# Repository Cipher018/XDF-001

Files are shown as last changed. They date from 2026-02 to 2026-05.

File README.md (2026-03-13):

# XDF-001

## Introduction

### What is XDF-001?

The **XDF-001**, or **Experimental Drone Fighter Model 001**, is a flight platform based on the P-51 Mustang airframe. Its experimental objective is to achieve a multi-role aircraft capable of both aerobatic flight and payload transport. Additionally, the XDF-001 platform seeks to demonstrate the viability of implementing simple autonomous capabilities in RC drones using vector operations, alongside data visualization via the **XDF-001 Control** application.

### Motivation

The motivation for this project stems from an interest in military aviation and aeronautics, as well as addressing the economic barriers within the RC aircraft community. Developing an aircraft within the ESP32 ecosystem helps overcome financial constraints, enabling the transition beyond typical 8-inch drones to larger-scale aircraft at equally competitive prices.

Another key motivation is the code's iterative potential; it can be adapted and modified for a myriad of missions and other types of aircraft and vehicles, allowing for extensive iteration and versatility.

### Objectives

The primary objective is to develop a fixed-wing platform based on the ESP32 ecosystem, capable of both radio control and simple autonomous maneuvers such as waypoint navigation or orbiting.

The secondary objectives are:

- Development of a telemetry visualization and control application for the flight platform.
- Study of various aerodynamic configurations to maximize the stability-to-top-speed ratio.
- Study of ESP32 behavior in handling real-time vector operations and autonomous capabilities.
- Development of a payload bay within the platform for payload transport.

### Architecture

As previously mentioned, the project is based on the ESP32 ecosystem and programmed using the Arduino IDE. However, communication between the ground ESP32 and the PC utilizes a binary system, enabling both command transmission and telemetry reception via USB serial. For a comprehensive study of the firmware architecture, please refer to the **[Documentation](Documentation/)** folder: check the diagrams section for data flows or the PDF section for function documentation.

## Project Parts

Below is a brief description of the repository's main folders and their contents:

### [CAD](CAD/)

Contains all CAD modeling files, including the root file modeled in FreeCAD and `.stp` files for the aircraft and PCB, as well as 3D models for the modules used.

<p align="center">
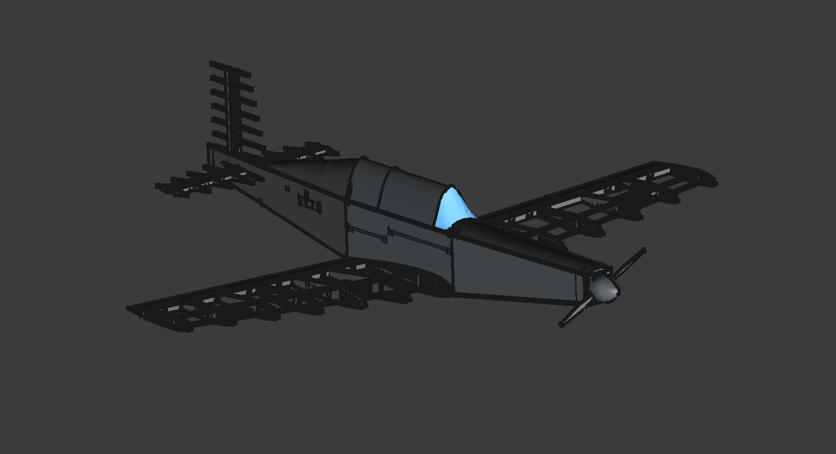
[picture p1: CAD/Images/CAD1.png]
CAD Model 1
  
  <br>
  <em>CAD Model 1</em>
</p>

<p align="center">
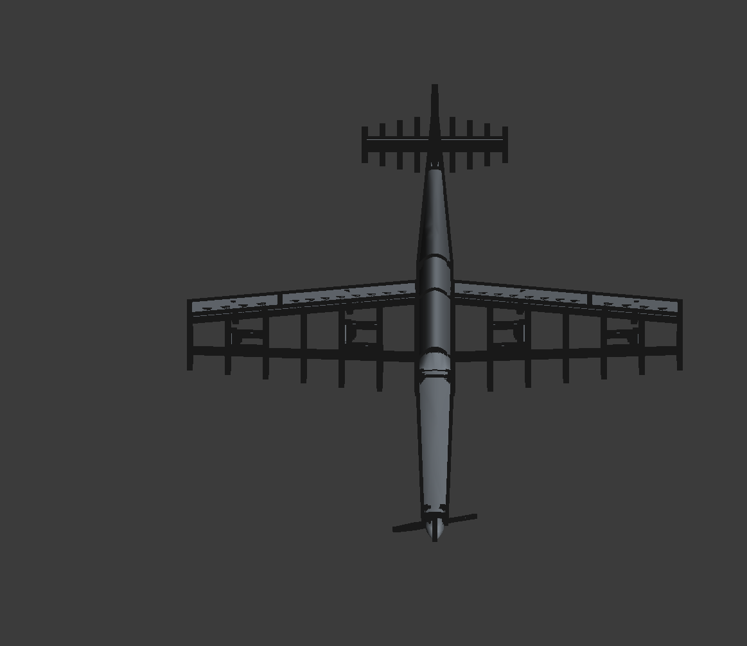
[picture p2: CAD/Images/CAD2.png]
CAD Model 2
  
  <br>
  <em>CAD Model 2</em>
</p>

### [Firmware](Firmware/)

Contains all ESP32 code, divided into air and ground sections. This includes communication functions, vector calculations, etc.

### [PCB](PCB/)

Contains all electronics-related files, including schematics, `.pcb` files, and manufacturing Gerbers.

<p align="center">
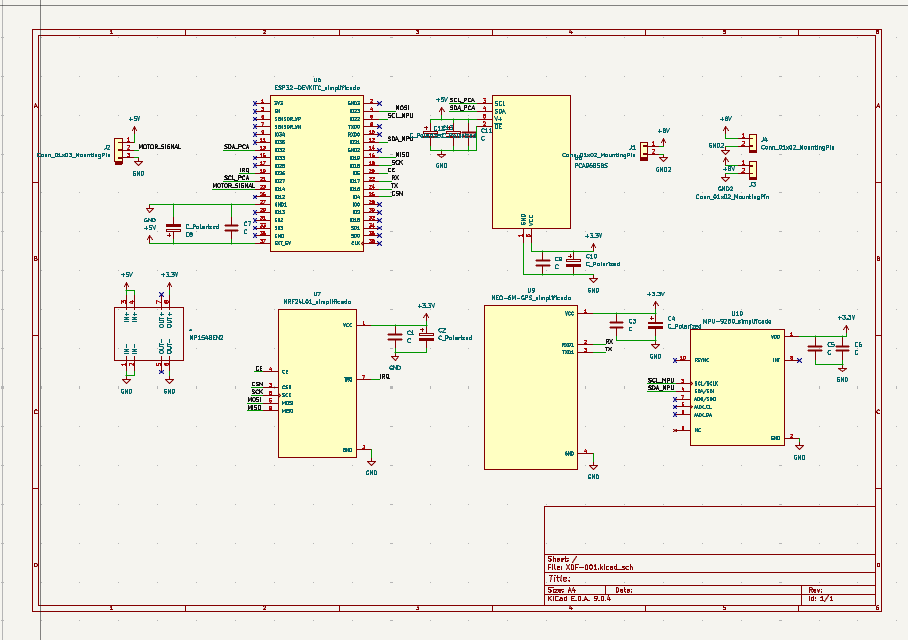
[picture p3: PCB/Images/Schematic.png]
PCB Schematic
  
  <br>
  <em>PCB Schematic</em>
</p>

<p align="center">
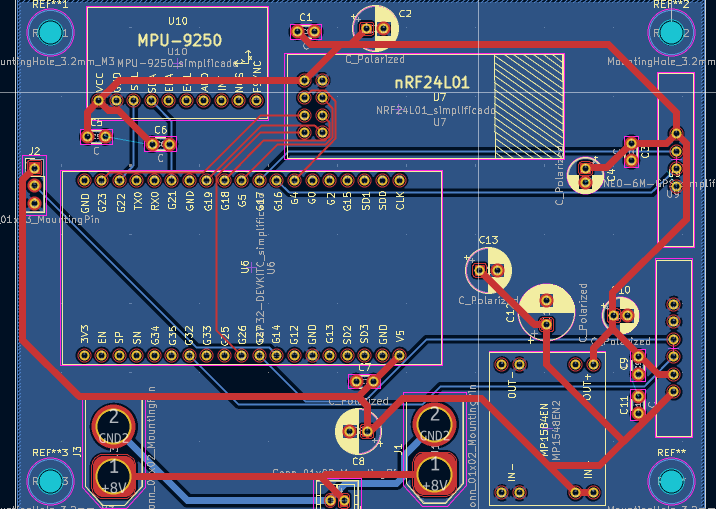
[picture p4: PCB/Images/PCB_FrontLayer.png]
PCB Front Layer
  
  <br>
  <em>PCB Front layer</em>
</p>

<p align="center">
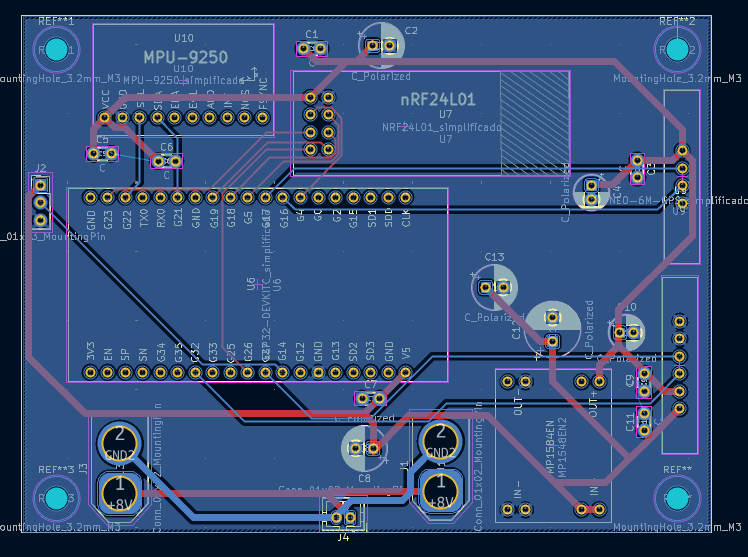
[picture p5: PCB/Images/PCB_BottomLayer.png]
PCB Back Layer
  
  <br>
  <em>PCB Back Layer</em>
</p>

<p align="center">
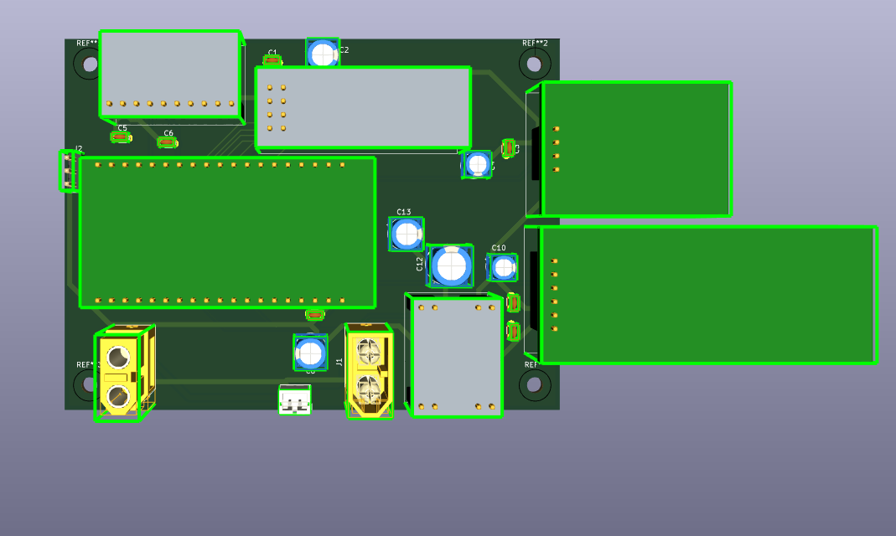
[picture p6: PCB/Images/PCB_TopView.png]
PCB Top view
  
  <br>
  <em>PCB Top view</em>
</p>

<p align="center">
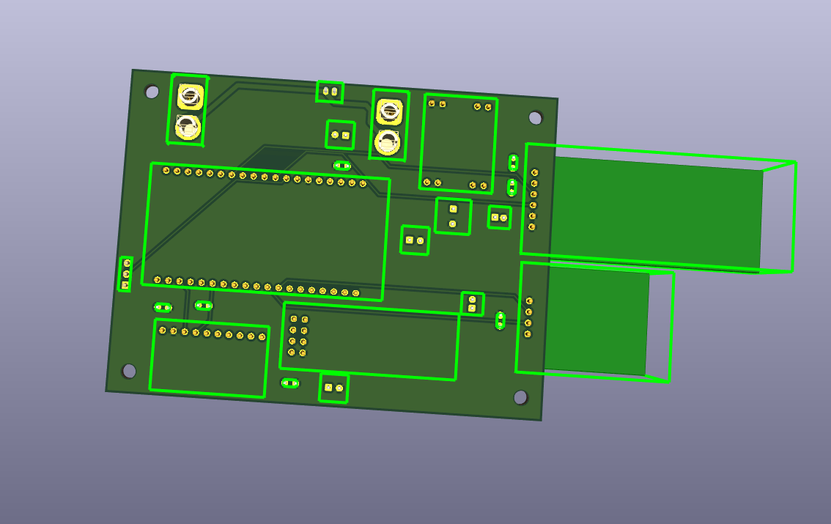
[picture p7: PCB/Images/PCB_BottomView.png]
PCB Bottom
  
  <br>
  <em>PCB Bottom view</em>
</p>

<p align="center">
  Wiring Diagram
  <br>
  <em>Referential Wiring Diagram of the aircraft</em>
</p>

### [XDF-001 Control](XDF-001_Control/)

Dedicated strictly to the visualization and control application. Contains all backend and frontend code.

### [References](References/)

Contains all structural references and concepts adopted from various creators for the project's construction.

### [Documentation](Documentation/)

Contains flowcharts and a detailed PDF explaining the application code, autonomous functions, and vector-based calculations.

### [Construction Manual](Construction%20Manual/)

PDF file detailing the aircraft construction method and key considerations for assembly.

## Changelog

### V0.0.0

Base project files have been exported, including code prototypes for both the ground and air sections. This release also includes the prototype for the control and telemetry application, as well as the PCB rendering, schematics, and CAD files.

## Roadmap

### V0.1.0

Completion of integration with Excel and SQL databases for the control and telemetry application.
Theoretical completion of the ground and air section code, enabling remote flight capabilities without telemetry and video visualization.

### V0.2.0

Achievement of initial flight tests, featuring full integration between the ground section and the control and telemetry application.
Initial implementation of autonomous functions, such as navigating to a designated point at a predefined altitude.

## FAQ

### What is the cost of the project?

The cost of the project varies depending on the dimensions of the flight platform and the components selected. For instance, opting to exclude the camera or telemetry functions can result in a cost of approximately $30. Conversely, selecting premium components can increase the cost to the order of $200 or more.

### Can I adapt this project?

Yes, under the license provided, I grant permission for the project to be modified to suit individual needs. In fact, adaptability is one of the core objectives of this project.

### What types of peripherals can I use to control the drone?

Any peripheral is acceptable provided it can be read by the ESP32 microcontroller. In this instance, a console controller was used, but joysticks, keyboards, mice, or any HID device are also compatible.

### How is the visualization and telemetry application used?

#### User Mode (Run Executable)

To use the application as a final user:

**Option A: Installer (Recommended)**

1. Navigate to `XDF-001_Control/out/make/squirrel.windows/x64/`.
2. Run `xdf-001_control-1.0.0 Setup.exe`.
3. The app will install and open automatically.

**Option B: Portable (Direct Run)**

1. Navigate to `XDF-001_Control/out/xdf-001_control-win32-x64/`.
2. Run `xdf-001_control.exe` directly.
3. No installation required. (You can also share the `out/make/zip` file).

#### Developer Mode (Run from Source)

If you want to modify the code or debug:

1. **Prerequisites**: Ensure [Node.js](https://nodejs.org/) (LTS) is installed.
2. Open a terminal in `XDF-001_Control`.
3. Install dependencies: `npm install`.
4. Start the app: `npm start`.

#### Build Mode (Create Executable)

To generate the `.exe` file yourself:

1. Follow the **Developer Mode** steps to set up the environment.
2. Run the build command: `npm run make`.
3. The output files will be created in the `out/` folder.

## Bill of Materials

| Item | Description | Quantity | Unit price | Total Price | Source | Running Total ($ with Tax) |
| --- | --- | --- | --- | --- | --- | --- |
| ESP-32 Devkit 38 pins | Dev board that will allow processing of telemetry, air-to-ground communication and autonomous operations based on vector operations | 1 | 4,23 | 4,23 | [Aliexpress](https://es.aliexpress.com/item/1005001838731651.html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"order"%3A"36"%2C"eval"%3A"1"%2C"fromPage"%3A"search"%7D&pdp_npi=6%40dis%21USD%213.34%213.34%21%21%213.34%213.34%21%4021033d9d17668726156532986ee92f%2112000030215458678%21sea%21CL%210%21ABX%211%210%21n_tag%3A-29910%3Bd%3Aeb55f528%3Bm03_new_user%3A-29895&curPageLogUid=kPFgvXo63lz3&utparam-url=scene%3Asearch%7Cquery_from%3A%7Cx_object_id%3A1005001838731651%7C_p_origin_prod%3A) | 5,03 |
| PCA9685 Servomotor Driver | Servomotor driver that allows control of up to 16 servomotors using only 2 pins, mainly used to avoid using all the pins of the ESP32 and for more sophisticated control via binary control | 1 | 1,2 | 1,2 | [Aliexpress](https://es.aliexpress.com/item/1005010790150348.html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,scm-url:1007.40050.354490.0,pvid:1402e862-8566-486e-90f8-f426f7e59b77,tpp_buckets:668%232846%238116%232002&pdp_ext_f=%7B"order"%3A"7"%2C"spu_best_type"%3A"price"%2C"eval"%3A"1"%2C"sceneId"%3A"30050"%2C"fromPage"%3A"recommend"%7D&pdp_npi=6%40dis%21USD%218.09%211.20%21%21%2155.58%218.25%21%402101e07217707498748102094ee684%2112000053516946348%21rec%21CL%21%21ABX%211%210%21n_tag%3A-29910%3Bd%3Aeb55f528%3Bm03_new_user%3A-29895%3BpisId%3A5000000197836568&utparam-url=scene%3ApcDetailTopMoreOtherSeller%7Cquery_from%3A%7Cx_object_id%3A1005010790150348%7C_p_origin_prod%3A) | 1,43 |
| nRF24l01+PLA Module | Radio module that allows medium-range air-to-ground communication without major interference; a PLA antenna is added to maximize range. | 2 | 2,31 | 4,62 | [Aliexpress](https://es.aliexpress.com/item/1005005392489486.html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"order"%3A"6"%2C"fromPage"%3A"search"%7D&pdp_npi=6%40dis%21USD%212.11%212.11%21%21%212.11%212.11%21%402103274e17668729080428683e0e67%2112000032873703259%21sea%21CL%210%21ABX%211%210%21n_tag%3A-29910%3Bd%3Aeb55f528%3Bm03_new_user%3A-29895) | 5,5 |
| NEO6M GPS Module | GPS module that allows knowing the exact position of the aircraft along with its speed and altitude, key for both vector calculation and telemetry | 1 | 2,33 | 2,33 | [Aliexpress](https://es.aliexpress.com/item/1005009301460295.html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"order"%3A"40"%2C"eval"%3A"1"%2C"fromPage"%3A"search"%7D&pdp_npi=6%40dis%21USD%2112.94%212.58%21%21%2190.14%2118.00%21%402101eee917668729646036661ea8d4%2112000048669875233%21sea%21CL%210%21ABX%211%210%21n_tag%3A-29910%3Bd%3Aeb55f528%3Bm03_new_user%3A-29895%3BpisId%3A5000000187458941&curPageLogUid=0pwpEmsQtlzq&utparam-url=scene%3Asearch%7Cquery_from%3A%7Cx_object_id%3A1005009301460295%7C_p_origin_prod%3A) | 2,77 |
| MP1584EN Module | The 3.3 Volt voltage regulator allows for the safe and continuous powering of sensitive modules such as the nrf24l01 directly from the VEC. | 1 | 0,67 | 0,67 | [Aliexpress](https://es.aliexpress.com/item/1005007510639297.html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"order"%3A"53"%2C"eval"%3A"1"%2C"fromPage"%3A"search"%7D&pdp_npi=6%40dis%21USD%210.69%210.69%21%21%210.69%210.69%21%402103110517668730162028434ee199%2112000041075639944%21sea%21CL%210%21ABX%211%210%21n_tag%3A-29910%3Bd%3Aeb55f528%3Bm03_new_user%3A-29895&curPageLogUid=SD7vrXFsh4I0&utparam-url=scene%3Asearch%7Cquery_from%3A%7Cx_object_id%3A1005007510639297%7C_p_origin_prod%3A) | 0,8 |
| MPU-9250 Module | Magnetometer, gyroscope and accelerometer that will allow knowing the orientation and acceleration that the plane suffers in flight, also key for vector calculation thanks to being able to know the heading | 1 | 2,31 | 2,31 | [Aliexpress](https://es.aliexpress.com/item/1005008322380169.html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"order"%3A"158"%2C"fromPage"%3A"search"%7D&pdp_npi=6%40dis%21USD%212.41%212.31%21%21%2116.59%2115.90%21%40210328db17707765362651852ee1c4%2112000044605517157%21sea%21CL%210%21ABX%211%210%21n_tag%3A-29910%3Bd%3Aeb55f528%3Bm03_new_user%3A-29895%3BpisId%3A5000000197836524) | 2,75 |
| 4 pcs MG90S Servomotor | Servomotors with metal gears that allow for high-performance and precise movement of control surfaces | 2 | 7,26 | 14,52 | [Aliexpress](https://es.aliexpress.com/item/1005006715645291.html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"order"%3A"1174"%2C"spu_best_type"%3A"order"%2C"eval"%3A"1"%2C"fromPage"%3A"search"%7D&pdp_npi=6%40dis%21USD%217.86%217.26%21%21%2154.03%2149.91%21%402101eede17707501484135239e3e2c%2112000038078824012%21sea%21CL%210%21ABX%211%210%21n_tag%3A-29910%3Bd%3Aeb55f528%3Bm03_new_user%3A-29895%3BpisId%3A5000000197836533&curPageLogUid=1rzUYNGeA38j&utparam-url=scene%3Asearch%7Cquery_from%3A%7Cx_object_id%3A1005006715645291%7C_p_origin_prod%3A&search_p4p_id=202602101102283078647985834520003281418_4) | 17,28 |
| NEEBRC 3542 1000KV  2-4S Outrunner Brushless Motor for RC Fixed Wing Airplane | A brushless motor that generates thrust for the aircraft was chosen in this case due to the aircraft's dimensions.It includes ESC and VEC which allows control via a microcontroller and voltage regulation from the LiPo battery. | 1 | 39,52 | 39,52 | [Aliexpress](https://es.aliexpress.com/item/1005010323659583.html) | 47,03 |
| AERONAUT CAM CARBON LIGHT 11/5 CLOCKWISE CW Popeller | Light carbon propeller designed to generate the maximum amount of thrust efficiently | 1 | 6,9 | 6,9 | [Lindinger](https://www.lindinger.at/en/AIRPLANES/ELECTRIC-POWERPLANTS/Propellers/Rigid-Propellers/AERONAUT-CAM-CARBON-LIGHT-11-5-CLOCKWISE-CW-Popeller/9709758) | 8,21 |
| 20pcs/lot nylon and tin-plated hinge board 12x24mm | Nylon hinges that allow free and controlled movement of the control surfaces | 2 | 0,99 | 1,98 | [Aliexpress](https://es.aliexpress.com/item/1005003378453697.html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"order"%3A"270"%2C"spu_best_type"%3A"price"%2C"eval"%3A"1"%2C"fromPage"%3A"search"%7D&pdp_npi=6%40dis%21USD%212.14%210.99%21%21%212.14%210.99%21%4021030a4b17668720604047323ed999%2112000025503609437%21sea%21CL%210%21ABX%211%210%21n_tag%3A-29910%3Bd%3Aeb55f528%3Bm03_new_user%3A-29895%3BpisId%3A5000000187458941&curPageLogUid=IF5w2F3Gs84q&utparam-url=scene%3Asearch%7Cquery_from%3A%7Cx_object_id%3A1005003378453697%7C_p_origin_prod%3A) | 2,36 |
| LiPo Battery 3S 11.1V 2200mAh XT60 | High-performance lithium polymer battery allowing sufficient voltage and current to be delivered to the motor thanks to its high discharge rate | 1 | 19,57 | 19,57 | [Aliexpress](https://es.aliexpress.com/item/1005010535385320.html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"order"%3A"1"%2C"eval"%3A"1"%2C"fromPage"%3A"search"%7D&pdp_npi=6%40dis%21CLP%2120721%2110600%21%21%21155.46%2179.53%21%402101ee6617664208804183520eaceb%2112000052735840324%21sea%21CL%210%21ABX%211%210%21n_tag%3A-29910%3Bd%3Aeb55f528%3Bm03_new_user%3A-29895%3BpisId%3A5000000187458941&curPageLogUid=aXInLcoxzZQB&utparam-url=scene%3Asearch%7Cquery_from%3A%7Cx_object_id%3A1005010535385320%7C_p_origin_prod%3A) | 23,29 |
| IMAX B3 PRO 7.4V/11.1V 2S 3S 110-240V Compact Lipo Battery Balance Charger | The charger allows you to both balance and charge the LiPo battery safely. | 1 | 4,62 | 4,62 | [Aliexpress](https://es.aliexpress.com/item/1005005136510204.html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"order"%3A"85"%2C"spu_best_type"%3A"order"%2C"eval"%3A"1"%2C"fromPage"%3A"search"%7D&pdp_npi=6%40dis%21USD%2123.83%217.36%21%21%21165.97%2151.29%21%4021033d1217668751951776208ee53b%2112000032033045913%21sea%21CL%210%21ABX%211%210%21n_tag%3A-29910%3Bd%3Aeb55f528%3Bm03_new_user%3A-29895%3BpisId%3A5000000187458893&curPageLogUid=egYPFsaawe16&utparam-url=scene%3Asearch%7Cquery_from%3A%7Cx_object_id%3A1005005136510204%7C_p_origin_prod%3A) | 5,5 |
| RC FPV Micro Camera AIO 5.8G 25MW 40CH 800TVL Transmitter LST-S4 + FPV Camera with OSD Parts for Racing Drone | AIO system for video recording and transmission, allows for a stable video signal | 1 | 14,65 | 14,65 | [Aliexpress](https://es.aliexpress.com/item/1005007250358286.html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"order"%3A"167"%2C"eval"%3A"1"%2C"fromPage"%3A"search"%7D&pdp_npi=6%40dis%21USD%2155.33%2114.65%21%21%21383.70%21101.61%21%402101e2b617675712158582197ee6a5%2112000039948782824%21sea%21CL%210%21ABX%211%210%21n_tag%3A-29910%3Bd%3Aeb55f528%3Bm03_new_user%3A-29895%3BpisId%3A5000000187458929&curPageLogUid=DFjszz4A4cBs&utparam-url=scene%3Asearch%7Cquery_from%3A%7Cx_object_id%3A1005007250358286%7C_p_origin_prod%3A) | 17,43 |
| RC832 Video Image Transmission Receiver, SKY 32S 5.8G FPV Wireless Upgrade | Video receiver to process the image and transform it into a USB signal for the application | 1 | 18,99 | 18,99 | [Aliexpress](https://es.aliexpress.com/item/4001042825044.html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"order"%3A"3"%2C"eval"%3A"1"%2C"fromPage"%3A"search"%7D&pdp_npi=6%40dis%21USD%2118.99%2118.99%21%21%2118.99%2118.99%21%402103128917677509412002200e4439%2110000013716139272%21sea%21CL%210%21ABX%211%210%21n_tag%3A-29910%3Bd%3Aeb55f528%3Bm03_new_user%3A-29895&curPageLogUid=PASqTpSbmsib&utparam-url=scene%3Asearch%7Cquery_from%3A%7Cx_object_id%3A4001042825044%7C_p_origin_prod%3A) | 22,6 |
| 1/16"*3"*42" Balsa Sheet | Construction material, in this case mainly for the fuselage | 2 | 2,78 | 5,56 | [Balsa USA](https://balsausa.com/collections/4-balsa-sheet/products/1-16-x-3-x-42-balsa-sheet) | 6,62 |
| 1/8"*3"*24" Balsa Sheet | Construction material, in this case mainly for the fuselage | 2 | 2,03 | 4,06 | [Balsa USA](https://balsausa.com/collections/3-balsawood-sheet/products/1-8-x-3-x-24-balsa-sheet) | 4,83 |
| 1/4"*3"*24" Balsa Sheet | Reinforcements for the control surfaces and fuselage | 1 | 3,16 | 3,16 | [Balsa USA](https://balsausa.com/collections/3-balsawood-sheet/products/1-4-x-3-x-24-balsa-sheet) | 3,76 |
| 1/8"*1/8"*36" Balsa Strip | Reinforcements for the control surfaces and fuselage | 4 | 0,61 | 2,44 | [Balsa USA](https://balsausa.com/collections/36-balsa-strips/products/1-8-x-1-8-x-36-balsa-stick) | 2,9 |
| 1/2"*1/2"*36" Balsa Strip | Reinforcements for the control surfaces and fuselage | 2 | 2,46 | 4,92 | [Balsa USA](https://balsausa.com/collections/36-balsa-strips/products/1-2-x-1-2-x-36-balsa-stick) | 5,85 |
| PCB | Circuit board to house all the electronics inside the aircraft | 1 | 12,1 | 12,1 | JLCPCB | 12,1 |
| M4x8 Screws | Metric machine screws (M3/M4), zinc plated steel, for mechanical fastening and structural joining | 8 | 0,08 | 0,64 | Local Hardware Store | 0,76 |
| M3x8 Screws | Metric machine screws (M3/M4), zinc plated steel, for mechanical fastening and structural joining | 34 | 0,06 | 2,04 | Local Hardware Store | 2,43 |
| M4x10 Screws | Metric machine screws (M3/M4), zinc plated steel, for mechanical fastening and structural joining | 8 | 0,09 | 0,72 | Local Hardware Store | 0,86 |
| M4x6 Screws | Metric machine screws (M3/M4), zinc plated steel, for mechanical fastening and structural joining | 4 | 0,08 | 0,32 | Local Hardware Store | 0,38 |
| M3x20 Screws | Metric machine screws (M3/M4), zinc plated steel, for mechanical fastening and structural joining | 4 | 0,1 | 0,4 | Local Hardware Store | 0,48 |
| M4x12 Screws | Metric machine screws (M3/M4), zinc plated steel, for mechanical fastening and structural joining | 8 | 0,1 | 0,8 | Local Hardware Store | 0,95 |
| XT60 Male conecctor | LiPo battery input connector, supplies power to the PCB main power rail. | 1 | 0,85 | 0,85 | Local Hardware Store | 1,01 |
| XT60 Female conector | High-current output connector, distributes power from the main rail to loads. | 1 | 0,85 | 0,85 | Local Hardware Store | 1,01 |
| JST Conector | Low-current signal connector for auxiliary peripherals like the FPV camera. | 1 | 0,15 | 0,15 | Local Hardware Store | 0,18 |
| 40 pins socket pack | Interconnection headers for module mounting and replacement on the PCB. | 2 | 0,6 | 1,2 | Local Hardware Store | 1,43 |
| Ceramic capacitor 10nf | High-frequency decoupling on the MPU9250 power supply line. | 1 | 0,08 | 0,08 | Local Hardware Store | 0,1 |
| Ceramic capacitor 100nf | Local decoupling on the power supply lines of all modules. | 7 | 0,07 | 0,49 | Local Hardware Store | 0,58 |
| Electrolitic capacitor 10uf | Mid-frequency filtering on the PCA9685 and NEO-6M logic supply lines. | 2 | 0,12 | 0,24 | Local Hardware Store | 0,29 |
| Electrolitic capacitor 100uf | Voltage stabilization on the ESP32 and NRF24L01 power rails. | 3 | 0,22 | 0,66 | Local Hardware Store | 0,79 |
| Electrolitic capacitor 470uf | Current spike absorption on the PCA9685 servo power rail. | 1 | 0,55 | 0,55 | Local Hardware Store | 0,65 |

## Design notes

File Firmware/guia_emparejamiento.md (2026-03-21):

# Seguridad C.A.D.I.: Guía de Emparejamiento y Configuración

Esta guía describe el proceso de "emparejamiento" entre las unidades **CADI_A** (Avión) y **CADI_G** (Tierra) utilizando una clave secreta compartida XXTEA almacenada en la Memoria No Volátil (NVS).

## Resumen

Para evitar el control no autorizado de la aeronave, todos los paquetes de comando y telemetría están cifrados mediante el algoritmo XXTEA. Ambas unidades deben compartir la misma clave de 128 bits (16 bytes).

Anteriormente, esta clave estaba grabada a fuego en el firmware. Para mejorar la seguridad, ahora se almacena en la NVS del ESP32, lo que permite que cada dron tenga una clave única sin necesidad de recompilar el código.

## Requisitos Previos

- Unidades CADI_A y CADI_G basadas en ESP32.
- Monitor Serial (ej. Monitor Serial de VS Code, PuTTY o el Monitor Serial de Arduino).
- Una cadena de 16 caracteres compartida (ej. `XDF001_SECRET_KEY`).

## Procedimiento de Emparejamiento

### 1. Conexión Serial

Conecte cada unidad a su computadora mediante USB. Abra una terminal serial a **115200 baudios**.

### 2. Configurar la Clave

Envíe el siguiente comando a través de la terminal serial:

```
SET_KEY:tu_clave_de_16_caracteres
```

> [!IMPORTANT]
> La clave DEBE tener exactamente 16 caracteres. Si es más corta, se rellenará con ceros. Si es más larga, se truncará.

**Ejemplo:**

```
SET_KEY:XDF001_SEC_2026!
```

### 3. Verificación

Al recibir el comando, la unidad responderá:
`[SEC] New key stored in NVS. Restarting...`

La unidad se reiniciará y cargará la nueva clave desde la NVS durante la fase de `setup()`.

### 4. Repetir para Ambas Unidades

Repita este proceso tanto para el **AeroPart** como para el **GrounPart**. Ambos deben tener la clave idéntica para comunicarse.

## Detalles Técnicos

- **Algoritmo:** XXTEA (Corrected Block TEA).
- **Almacenamiento:** Librería `Preferences` (Namespace: `"pairing"`, Clave: `"shared_key"`).
- **Verificación:** El sistema utiliza una cabecera `MAGIC_CMD` (0xAA) y `MAGIC_TELEM` (0xBB). Si el descifrado falla (ej. las claves no coinciden), la verificación CRC fallará y el paquete será descartado.

## Solución de Problemas

- **Sin comunicación:** Verifique que las claves coincidan exactamente en ambas unidades (distingue mayúsculas y minúsculas).
- **Pérdida de Paquetes:** Asegúrese de que las antenas nRF24L01 estén bien conectadas y que la `lossRate` en el encabezado de la GCS sea inferior al 20%.
- **Restablecimiento:** Para cambiar una clave, debe sobrescribirla manualmente con `SET_KEY` o realizar un borrado de flash del ESP32.

---

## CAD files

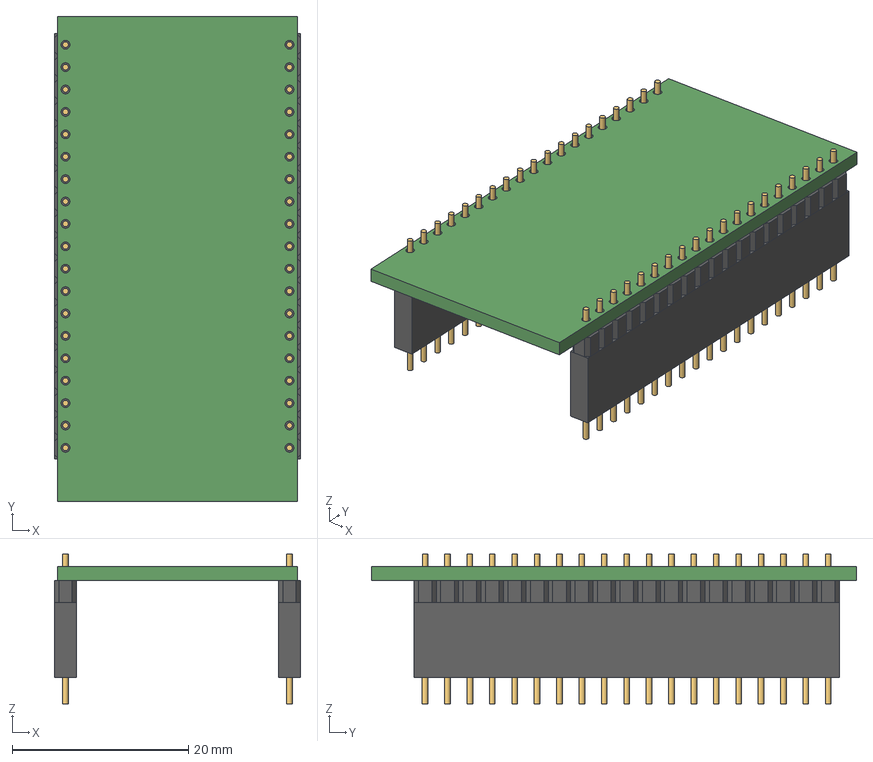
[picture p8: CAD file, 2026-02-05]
CAD/Root file/esp32-Assembly.step
27.9 x 55.0 x 17.0 mm
LCS_Origin x 5
ESP32
Parte plastica x 4
Metal superior x 38
Metal inferior x 40
LCS_PH1 x 2
Parte metalica x 38

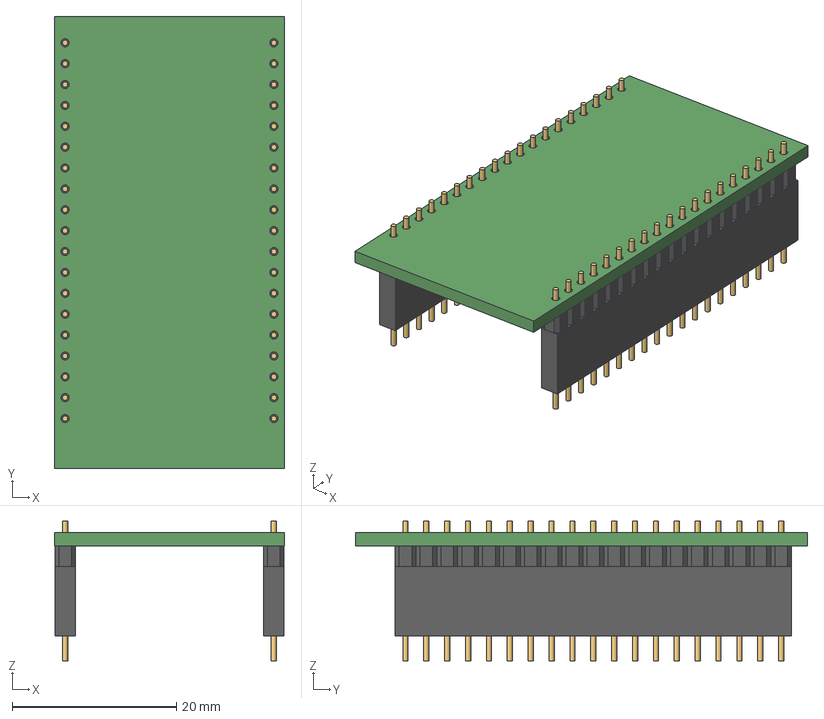
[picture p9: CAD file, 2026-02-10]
CAD/Assembly/esp32-Assembly.step
28.0 x 55.0 x 17.0 mm
LCS_Origin x 5
ESP32
Parte plastica x 4
Metal superior x 38
Metal inferior x 40
LCS_PH1 x 2
Parte metalica x 38

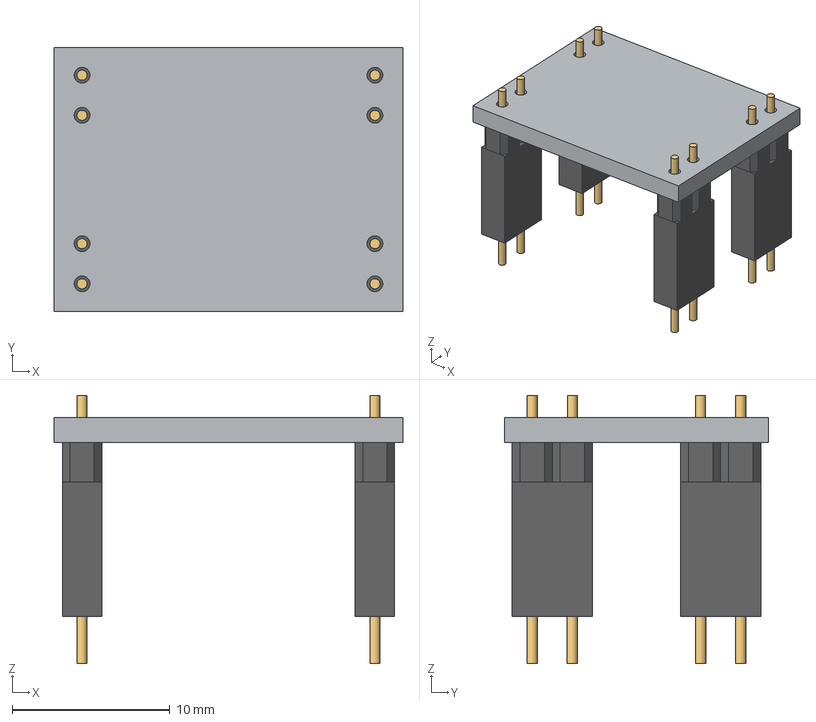
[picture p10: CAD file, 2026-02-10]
CAD/Assembly/MP1584EN-Assembly.step
22.1 x 16.7 x 17.0 mm
LCS_Origin x 9
MP1584 EN
Parte plastica x 8
LCS_PH1 x 4
Metal superior x 8
Metal inferior x 8
Parte metalica x 8

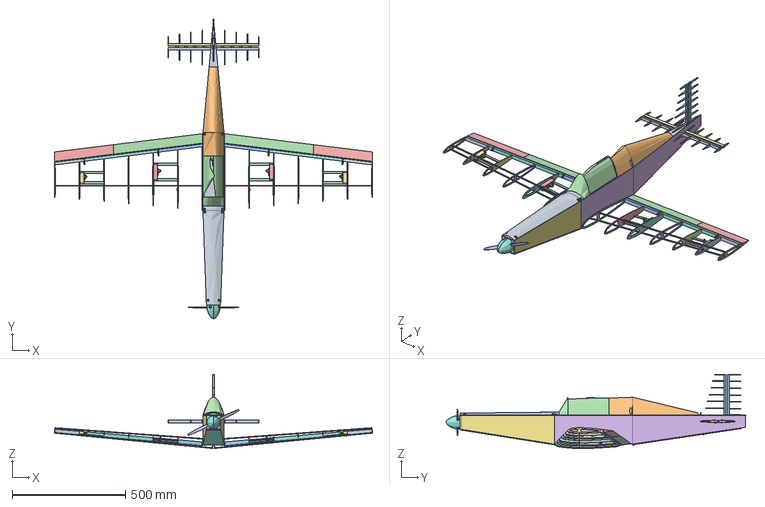
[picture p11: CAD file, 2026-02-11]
CAD/Assembly/XDF-001.step
1402.2 x 1321.6 x 327.0 mm

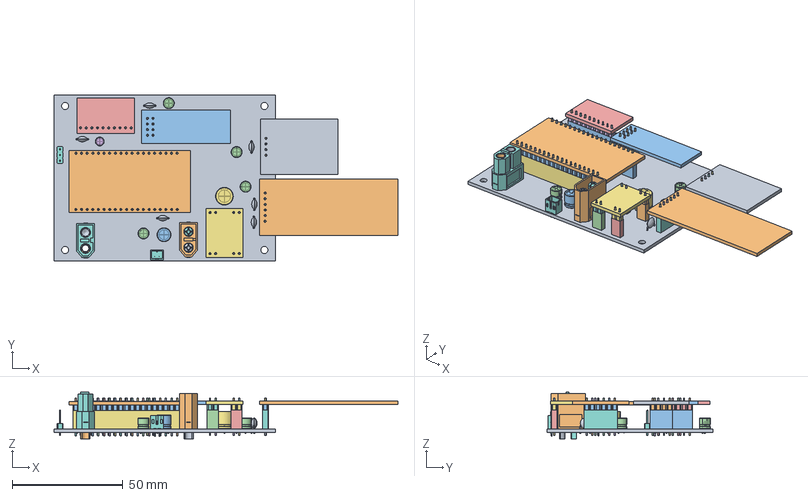
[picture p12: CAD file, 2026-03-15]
CAD/Root file/PCB Parts/PCB.FCStd
155.3 x 75.0 x 21.2 mm
Pcb_21ec
PCA9685
Parte plastica
Metal superior
Metal superior001
Metal superior002
Metal superior003
Metal superior004
Metal superior005
Metal inferior
Metal inferior001
Metal inferior002
Metal inferior003
Metal inferior004
Metal inferior005
Parte plastica001
Parte metalica
Parte metalica001
Parte metalica002
Parte metalica003
Parte metalica004
Parte metalica005
MP1584 EN
Parte plastica002
Metal superior006
Metal superior007
Metal inferior006
Metal inferior007
Parte plastica003
Metal superior008
Metal superior009
Metal inferior008
Metal inferior009
Parte plastica004
Metal superior010
Metal superior011
Metal inferior010
Metal inferior011
Parte plastica005
Metal superior012
Metal superior013
Metal inferior012
Metal inferior013
Parte plastica006
Parte metalica006
Parte metalica007
Parte plastica007
Parte metalica008
Parte metalica009
Parte plastica008
Parte metalica010
Parte metalica011
Parte plastica009
Parte metalica012
Parte metalica013
J4_JST_B2B_PH_K_095a3a355ae0
C5_C_Disc_D50mm_W25mm_P500mm_0bf9d0a9a681 x 6
ESP32
Parte plastica010
Metal superior014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

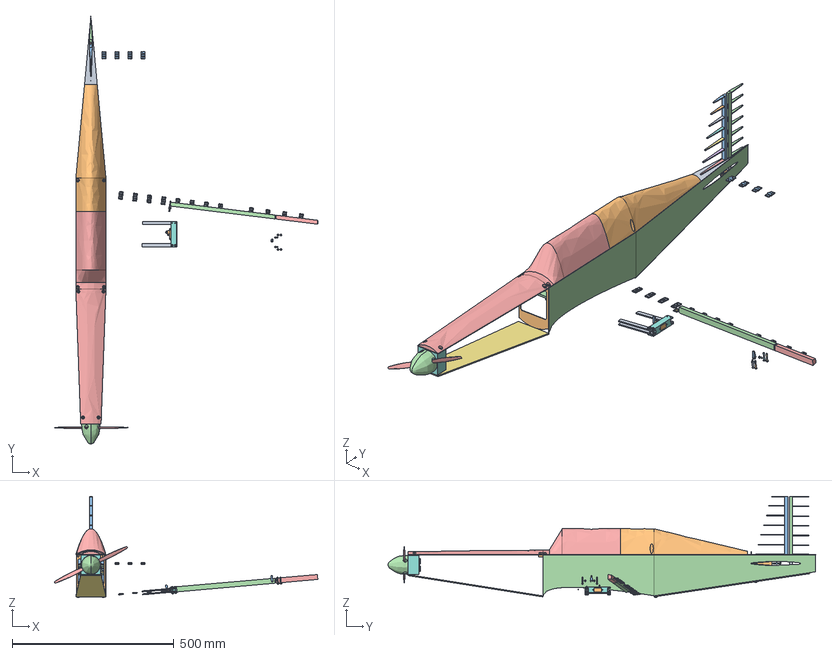
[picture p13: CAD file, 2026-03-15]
CAD/Root file/XDF-001.FCStd
814.3 x 1321.6 x 312.8 mm
Fuselaje Superior
Union B
Union C
Paredes
M4x8-Tornillo
M4x8-Tornillo206
M4x8-Tornillo207
M4x8-Tornillo208
Bisagra x 12
L1
Bisagra estabilizadores x 4
Montura PCB
M3x8-Tornillo
M3x8-Tornillo2409
Tarugo
Montura servomotor x 3
Soporte montura servomotor x 3
Servomotor x 3
Brazo servomotor x 4
M3x8-Tornillo2548
M3x8-Tornillo2549
M3x8-Tornillo2550
M3x8-Tornillo2551
M3x8-Tornillo2552
M3x8-Tornillo2553
M3x8-Tornillo2554
M3x8-Tornillo2555
Larguero trasero002
Larguero trasero003
Soporte Horn
Servo Horn
Union A
Motor Brushless
Union motor
M4x10-Tornillo
M4x6-Tornillo
M4x10-Tornillo117
M4x6-Tornillo145
M4x6-Tornillo146
M4x10-Tornillo118
M4x6-Tornillo147
M4x10-Tornillo123
Fuselaje superior 2
Nariz
Caparazon tortuga 2
M4x8-Tornillo209
M4x8-Tornillo210
M4x8-Tornillo211
M4x8-Tornillo212
Caparazon tortuga 1
Refuerzo Fijo EV
Refuerzo Movil EV
V1
V2
V3
V4
V5
V6
V7
V´ x 7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

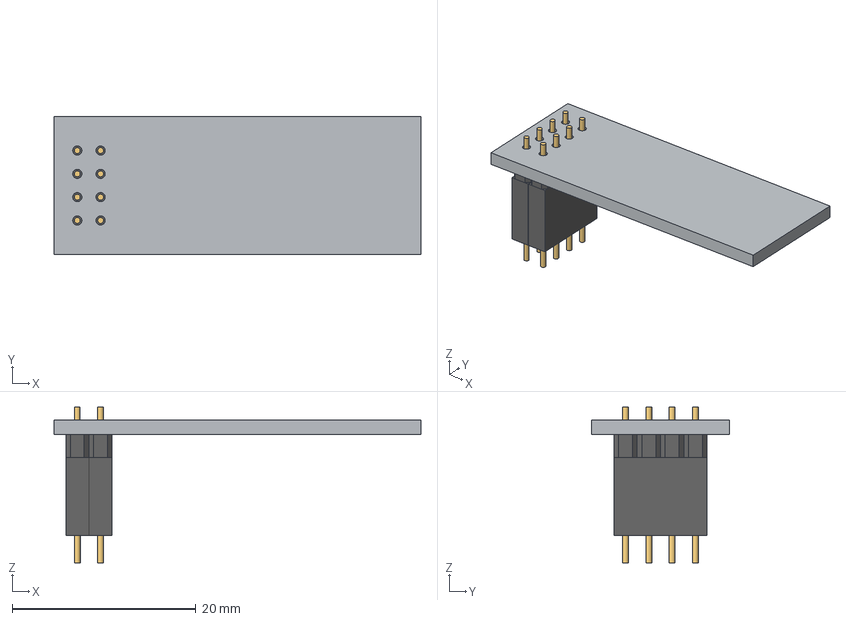
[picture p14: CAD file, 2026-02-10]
CAD/Assembly/NRF24L01.step
40.0 x 15.0 x 17.0 mm
LCS_Origin x 5
Nrf24l01
Parte plastica x 4
LCS_PH1 x 2
Metal superior x 8
Metal inferior x 8
Parte metalica x 8

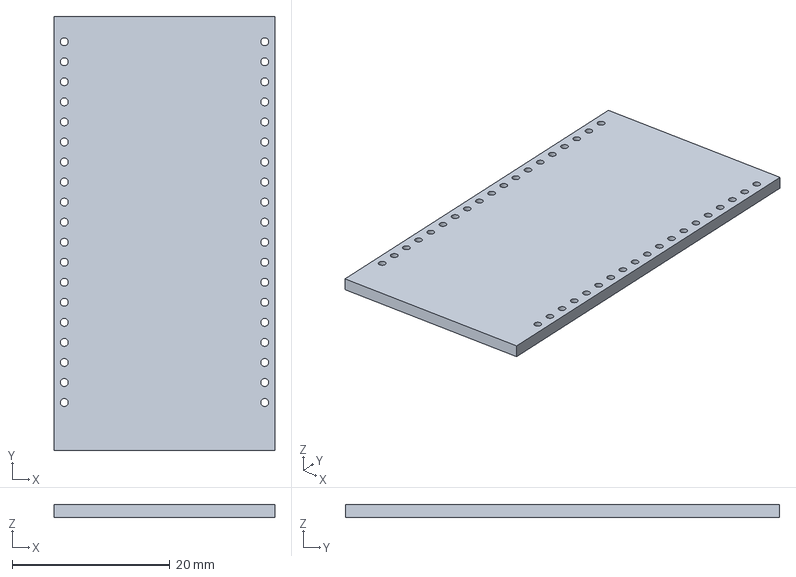
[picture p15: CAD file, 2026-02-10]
CAD/Root file/PCB Parts/esp32.FCStd
28.0 x 55.0 x 1.60 mm

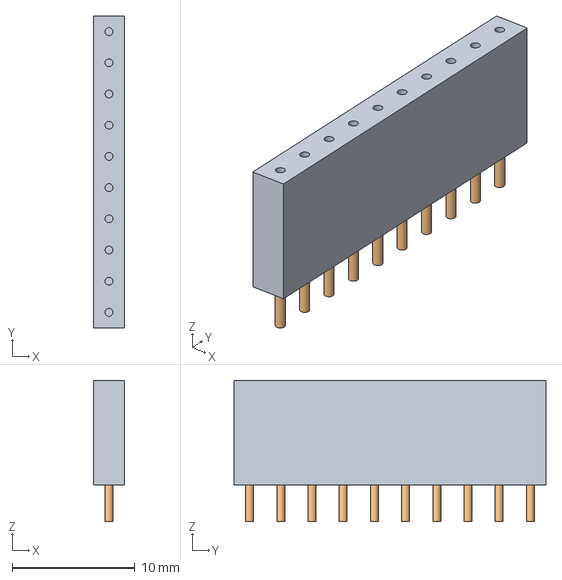
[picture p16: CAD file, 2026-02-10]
CAD/Root file/PCB Parts/Pin socket 1x10.FCStd
2.50 x 25.4 x 11.5 mm
Parte plastica
Parte metalica x 10

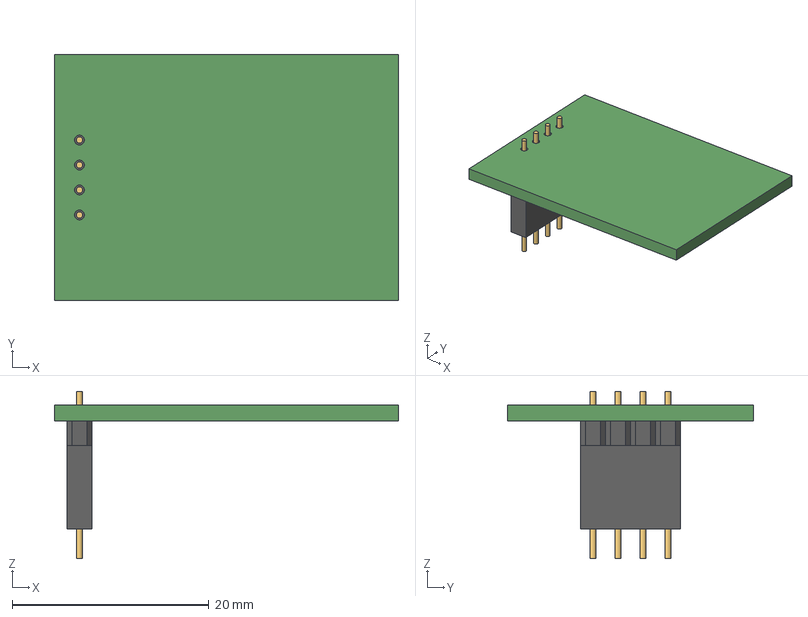
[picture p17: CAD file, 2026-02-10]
CAD/Assembly/NEO6M GPS.step
35.0 x 25.0 x 17.0 mm
LCS_Origin x 3
NEO6M
Parte plastica x 2
LCS_PH1
Metal superior x 4
Metal inferior x 4
Parte metalica x 4

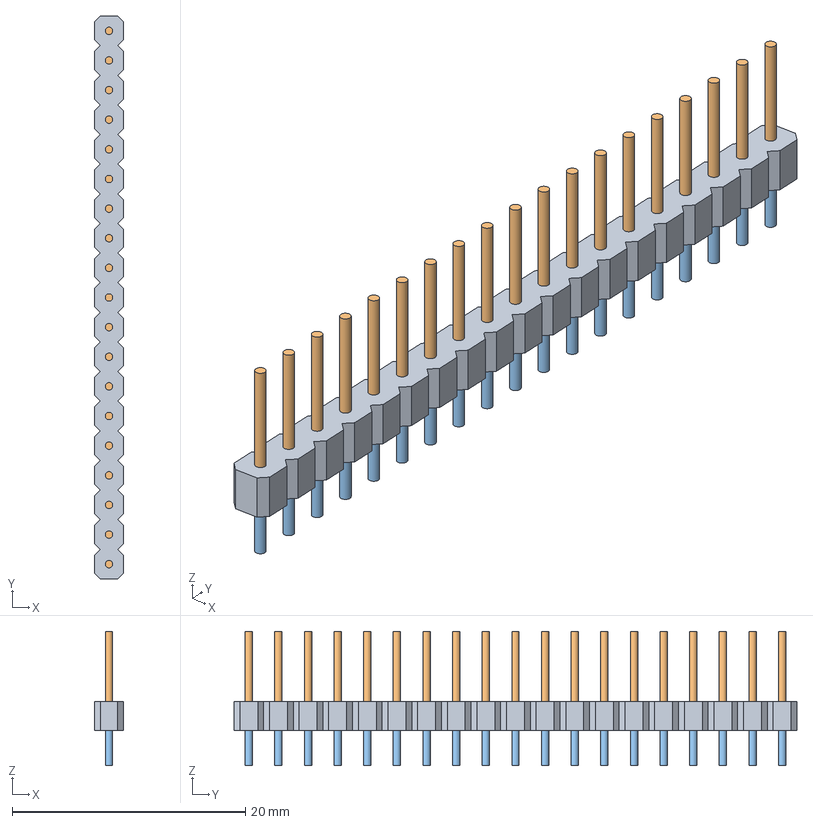
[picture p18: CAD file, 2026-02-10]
CAD/Root file/PCB Parts/Pin Header 1x18.FCStd
2.50 x 48.3 x 11.5 mm
Parte plastica
Metal superior x 19
Metal inferior x 20

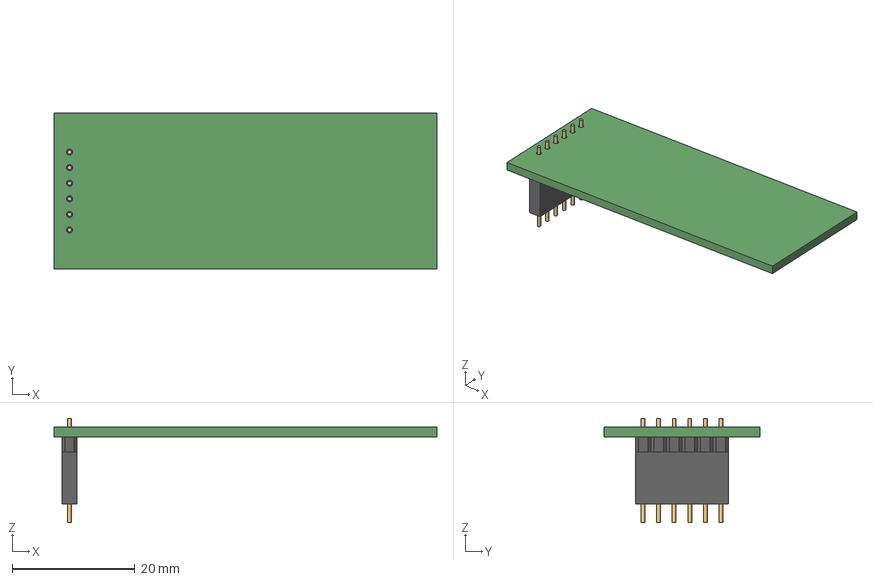
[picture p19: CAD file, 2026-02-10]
CAD/Assembly/PCA9685.step
62.5 x 25.5 x 17.0 mm
LCS_Origin x 3
PCA9685
Parte plastica x 2
LCS_PH1
Metal superior x 6
Metal inferior x 6
Parte metalica x 6

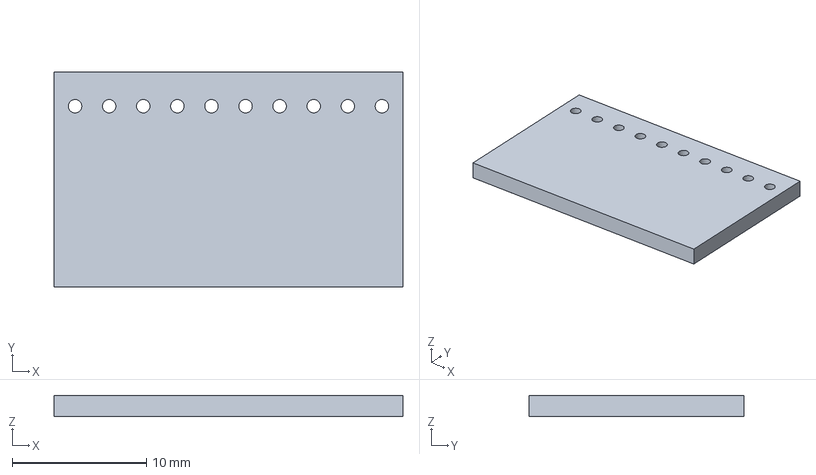
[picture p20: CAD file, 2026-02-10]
CAD/Root file/PCB Parts/MPU9250.FCStd
26.0 x 16.0 x 1.60 mm

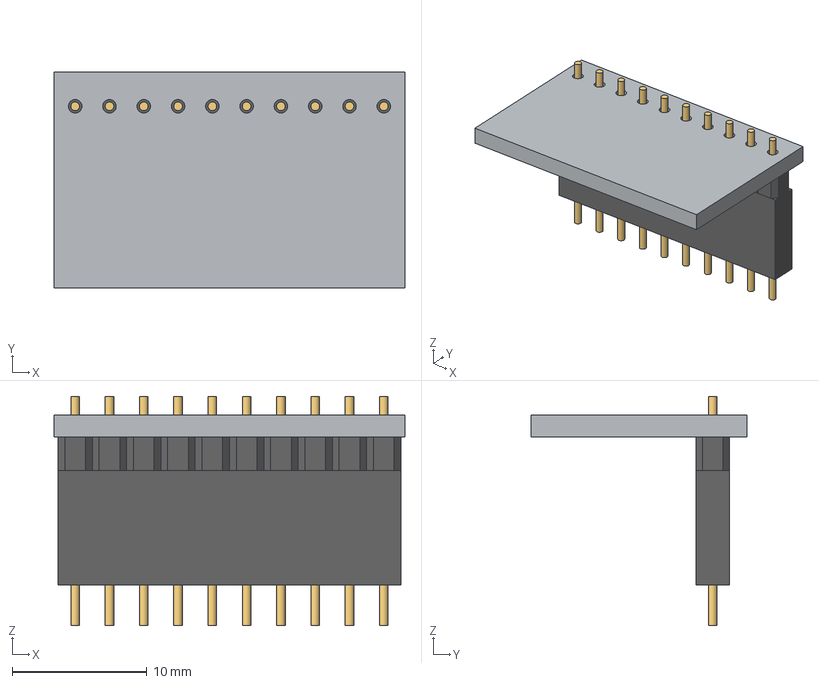
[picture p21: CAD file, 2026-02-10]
CAD/Assembly/MPU9250.step
26.0 x 16.0 x 17.0 mm
LCS_Origin x 3
Cuerpo
Parte plastica x 2
LCS_PH1
Metal superior x 10
Metal inferior x 10
Parte metalica x 10

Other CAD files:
CAD/Root file/Plane Parts/Ala.FCStd
CAD/Root file/PCB Parts/Pin socket 1x02.FCStd
CAD/Root file/PCB Parts/Pin Header 1x10.FCStd
CAD/Root file/PCB Parts/Pin Header 1x06.FCStd
CAD/Root file/PCB Parts/MP1584EN.FCStd
CAD/Root file/PCB Parts/NEO6M GPS.FCStd
CAD/Root file/PCB Parts/NRF24L01FCStd.FCStd
CAD/Root file/PCB Parts/PCA9685.FCStd
CAD/Root file/PCB Parts/Pin Header 1x02.FCStd
CAD/Root file/PCB Parts/Pin Header 1x04.FCStd
CAD/Root file/PCB Parts/Pin socket 1x04.FCStd
CAD/Root file/PCB Parts/Pin socket 1x06.FCStd
CAD/Root file/PCB Parts/Pin socket 1x18.FCStd

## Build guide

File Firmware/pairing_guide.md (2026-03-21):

# C.A.D.I. Security: XXTEA Pairing & Configuration Guide

This guide describes the process of "pairing" the **CADI_A** (Aircraft) and **CADI_G** (Ground) units using a shared XXTEA secret key stored in Non-Volatile Storage (NVS).

## Overview

To prevent unauthorized control of the aircraft, all command and telemetry packets are encrypted using the XXTEA algorithm. Both units must share the same 128-bit (16-byte) key. 

Previously, this key was hardcoded in the firmware. For improved security, it is now stored in the ESP32's NVS, allowing each drone to have a unique key without recompiling the code.

## Prerequisites

- ESP32-based CADI_A and CADI_G units.
- Serial Monitor (e.g., VS Code Serial Monitor, PuTTY, or Arduino Serial Monitor).
- Shared 16-character string (e.g., `XDF001_SECRET_KEY`).

## Pairing Procedure

### 1. Connect to Serial
Connect each unit to your computer via USB. Open a serial terminal at **115200 baud**.

### 2. Set the Key
Send the following command through the serial terminal:

```
SET_KEY:your_16_char_key
```

> [!IMPORTANT]
> The key MUST be exactly 16 characters long. If it is shorter, it will be padded with zeros. If it is longer, it will be truncated.

**Example:**
```
SET_KEY:XDF001_SEC_2026!
```

### 3. Verification
Upon receiving the command, the unit will respond with:
`[SEC] New key stored in NVS. Restarting...`

The unit will reboot and load the new key from NVS during the `setup()` phase.

### 4. Repeat for Both Units
Repeat this process for both the **AeroPart** and the **GrounPart**. Both must have the identical key to communicate.

## Technical Details

- **Algorithm:** XXTEA (Corrected Block TEA).
- **Storage:** `Preferences` library (Namespace: `"pairing"`, Key: `"shared_key"`).
- **Verification:** The system uses a `MAGIC_CMD` (0xAA) and `MAGIC_TELEM` (0xBB) header. If decryption failes (e.g., keys don't match), the CRC check will fail and the packet will be discarded.

## Troubleshooting

- **No communication:** Double-check that the keys match exactly on both units (case-sensitive).
- **Packet Loss:** Ensure the nRF24L01 antennas are properly connected and the `lossRate` in the GCS header is below 20%.
- **Resetting:** To clear a key, you must manually overwrite it with `SET_KEY` or perform an ESP32 flash erase.

---
*C.A.D.I. - Secure Unmanned Systems Integration*

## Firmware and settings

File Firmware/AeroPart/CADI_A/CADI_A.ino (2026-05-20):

#include <mpu9250.h>
#include <Preferences.h> // [F5] NVS key storage
#include <Adafruit_PWMServoDriver.h>
#include <ESP32Servo.h>
#include <RF24.h>
#include <SPI.h>
#include <TinyGPSPlus.h>
#include <Wire.h>
#include <nRF24L01.h>

// ═══════════════════════════════════════════════════════
// TELEMETRY PACKET — OPTIMIZADO
// Tamaño: 4+4+2+2+2+2+2+2+2+2 = 24 bytes (límite nRF24: 32B)
// Conversiones para campos int16:
//   ángulos   × 10  → 0.1° resolución
//   gforce    × 100 → 0.01G resolución
//   velocidad × 100 → 0.01 m/s resolución
// ═══════════════════════════════════════════════════════
struct __attribute__((packed)) TelemetryPacket {
  float   latitude;     // 4B — float necesario (6 decimales GPS)
  float   longitude;    // 4B — float necesario (6 decimales GPS)
  int16_t altitude;     // 2B — metros × 10  (−3276m a +3276m, 0.1m res)
  int16_t heading;      // 2B — grados × 10  (0 a 3599 → 0° a 359.9°)
  int16_t pitch;        // 2B — grados × 10  (−900 a +900 → −90° a +90°)
  int16_t roll;         // 2B — grados × 10  (−1800 a +1800)
  int16_t gforce;       // 2B — G × 100      (0 a 800 → 0G a 8G)
  int16_t velocityX;    // 2B — m/s × 100    (−5000 a +5000 → ±50 m/s)
  int16_t velocityY;    // 2B — m/s × 100
  int16_t velocityZ;    // 2B — m/s × 100
  uint8_t seq;          // 1B — Contador incremental para detectar pérdida [F3]
  uint8_t _pad[3];      // 3B — padding: 25→28 bytes (múltiplo de 4 para XXTEA)
};                      // Total: 28 bytes ✓

TelemetryPacket telemPkt;

// ═══════════════════════════════════════════════════════
// DUBINS AND VECTOR CLASS
// ═══════════════════════════════════════════════════════
class Vector3D {
public:
  float x, y, z;
  Vector3D(float _x = 0, float _y = 0, float _z = 0) : x(_x), y(_y), z(_z) {}
  Vector3D operator-(const Vector3D &v) const { return Vector3D(x - v.x, y - v.y, z - v.z); }
  Vector3D operator+(const Vector3D &v) const { return Vector3D(x + v.x, y + v.y, z + v.z); }
  Vector3D operator*(float s) const { return Vector3D(x * s, y * s, z * s); }
  float magnitude() const { return sqrtf(x * x + y * y + z * z); }
  Vector3D normalize() const {
    float mag = magnitude();
    if (mag < 0.001f) return Vector3D(0, 0, 0);
    return Vector3D(x / mag, y / mag, z / mag);
  }
  float dot(const Vector3D &v) const { return x * v.x + y * v.y + z * v.z; }
  Vector3D cross(const Vector3D &v) const {
    return Vector3D(y * v.z - z * v.y, z * v.x - x * v.z, x * v.y - y * v.x);
  }
};

// ── Global Mission State ──
const int MAX_WAYPOINTS = 16;
struct __attribute__((packed)) RouteWaypoint {
  float lat;
  float lon;
  float alt;
  uint8_t mode;      // 1=Waypoint, 2=Orbit
  uint8_t direction; // 0=CCW, 1=CW
  float radius;
};

RouteWaypoint waypointRoute[MAX_WAYPOINTS];
int waypointCount = 0;
int waypointIndex = 0;
bool routeLoop     = false;

enum NavigationMode { MODE_MANUAL = 0, MODE_WAYPOINT = 1, MODE_ORBIT = 2 };
NavigationMode currentMode = MODE_MANUAL;

// ═══════════════════════════════════════════════════════
// KALMAN FILTER — ACTITUD (pitch, roll, yaw)
// Modelo de 2 estados por eje: [ángulo, bias_gyro]
// ═══════════════════════════════════════════════════════
class KalmanAttitude {
public:
  KalmanAttitude(float q_angle = 0.001f,
                 float q_bias  = 0.003f,
                 float r_meas  = 0.03f)
    : Q_angle(q_angle), Q_bias(q_bias), R_meas(r_meas)
    , angle(0.0f), bias(0.0f)
  {
    P[0][0] = 0.0f; P[0][1] = 0.0f;
    P[1][0] = 0.0f; P[1][1] = 0.0f;
  }

  float update(float gyroRate, float measurement, float dt) {
    float rate  = gyroRate - bias;
    angle      += rate * dt;

    P[0][0] += dt * (dt * P[1][1] - P[0][1] - P[1][0] + Q_angle);
    P[0][1] -= dt * P[1][1];
    P[1][0] -= dt * P[1][1];
    P[1][1] += Q_bias * dt;

    float S  = P[0][0] + R_meas;
    float K0 = P[0][0] / S;
    float K1 = P[1][0] / S;

    float innovation = measurement - angle;
    angle += K0 * innovation;
    bias  += K1 * innovation;

    float P00_temp = P[0][0];
    float P01_temp = P[0][1];
    P[0][0] -= K0 * P00_temp;
    P[0][1] -= K0 * P01_temp;
    P[1][0] -= K1 * P00_temp;
    P[1][1] -= K1 * P01_temp;

    return angle;
  }

  void setAngle(float a) { angle = a; }
  float getAngle()  const { return angle; }
  float getBias()   const { return bias;  }

private:
  float Q_angle, Q_bias, R_meas;
  float angle, bias;
  float P[2][2];
};

KalmanAttitude kalmanPitch(0.001f, 0.003f, 0.03f);
KalmanAttitude kalmanRoll (0.001f, 0.003f, 0.03f);
KalmanAttitude kalmanYaw  (0.001f, 0.003f, 0.5f);  // mag: más ruido

// ═══════════════════════════════════════════════════════
// ESTIMACIÓN DE VELOCIDAD — Fusión GPS + IMU + Kalman
// ═══════════════════════════════════════════════════════
const float GPS_WEIGHT      = 0.3f;
const float MAX_VEL_GPS     = 60.0f;
const int   VEL_SMOOTH_SIZE = 3;

class KalmanVelocity {
public:
  KalmanVelocity(float q = 0.1f, float r = 1.5f)
    : _q(q), _r(r), _x(0.0f), _p(1.0f) {}

  float update(float measurement) {
    _p += _q;
    float k = _p / (_p + _r);
    _x = _x + k * (measurement - _x);
    _p = (1.0f - k) * _p;
    return _x;
  }

  void  setState(float x) { _x = x; _p = 1.0f; }
  float getState()  const { return _x; }

private:
  float _q, _r, _x, _p;
};

KalmanVelocity kfVx, kfVy, kfVz;

// ═══════════════════════════════════════════════════════
// HARDWARE DEFINITIONS
// ═══════════════════════════════════════════════════════
Servo esc;
#define ESC_PIN 14

int servo1Pos = 90, servo2Pos = 90, servo3Pos = 90, servo4Pos = 90;
int servo5Pos = 90, servo6Pos = 90, servo7Pos = 90, servo8Pos = 90;

TinyGPSPlus gps;
bfs::Mpu9250  mpu;

#define GPS_SERIAL Serial2
#define GPS_RX 17
#define GPS_TX 16

#define CE_PIN  5
#define CSN_PIN 4
RF24 radio(CE_PIN, CSN_PIN);
const byte pipeRX[6] = "CMD01";
const byte pipeTX[6] = "TEL01";

// ═══════════════════════════════════════════════════════
// FHSS AND CHANNELS (Salto de frecuencia por software)
// ═══════════════════════════════════════════════════════
const uint8_t fhssChannels[8] = { 10, 25, 40, 55, 70, 85, 100, 115 };
uint8_t currentChannelIdx = 0;
unsigned long lastPacketReceivedMs = 0;

// ═══════════════════════════════════════════════════════
// SECURITY (XXTEA)
// ═══════════════════════════════════════════════════════
uint32_t sharedKey[4] = { 0x58444630, 0x30314B45, 0x595F3230, 0x32362121 }; // "XDF001KEY_2026!!" en hex
#define XXTEA_DELTA 0x9e3779b9
#define XXTEA_MX (((z>>5^y<<2) + (y>>3^z<<4)) ^ ((sum^y) + (sharedKey[(p&3)^e] ^ z)))

void btea(uint32_t *v, int n) {
  uint32_t y, z, sum;
  unsigned p, rounds, e;
  if (n > 1) {
    rounds = 6 + 52/n;
    sum = 0;
    z = v[n-1];
    do {
      sum += XXTEA_DELTA;
      e = (sum >> 2) & 3;
      for (p=0; p<n-1; p++) {
        y = v[p+1];
        z = v[p] += XXTEA_MX;
      }
      y = v[0];
      z = v[n-1] += XXTEA_MX;
    } while (--rounds);
  } else if (n < -1) {
    n = -n;
    rounds = 6 + 52/n;
    sum = rounds*XXTEA_DELTA;
    y = v[0];
    do {
      e = (sum >> 2) & 3;
      for (p=n-1; p>0; p--) {
        z = v[p-1];
        y = v[p] -= XXTEA_MX;
      }
      z = v[n-1];
      y = v[0] -= XXTEA_MX;
      sum -= XXTEA_DELTA;
    } while (--rounds);
  }
}

// ── Headers Seguros ──
const uint8_t MAGIC_CMD   = 0xAA;
const uint8_t MAGIC_TELEM = 0xBB;
const uint8_t MAGIC_WP    = 0xAC;

struct __attribute__((packed)) SecureCommand {
  uint8_t  magic;
  uint8_t  seq;
  uint16_t crc;
  int16_t  targetRoll;
  int16_t  targetPitch;
  int16_t  targetYaw;
  int16_t  targetThrottle;
  float    homeLat;
  float    homeLon;
  int16_t  declinationX10;
  uint8_t  navMode;        // 0=MANUAL, 1=WAYPOINT, 2=ORBIT
  uint8_t  cmdFlags;       // Bit 0 = Reset route index
}; // Total: 24 bytes (6 words)

struct __attribute__((packed)) SecureWaypointPacket {
  uint8_t  magic;          // MAGIC_WP = 0xAC
  uint8_t  seq;
  uint16_t crc;
  uint8_t  wpIndex;        // 0..15
  uint8_t  totalWps;
  uint8_t  routeLoop;      // 0=no, 1=yes
  uint8_t  mode;           // NavigationMode (0=MANUAL, 1=WAYPOINT, 2=ORBIT)
  RouteWaypoint wp;        // 18 bytes
  uint8_t  _pad[2];        // Pad to 28 bytes (multiple of 4)
}; // Total: 28 bytes (7 words)

struct __attribute__((packed)) SecureTelemetry {
  uint8_t  magic;
  uint8_t  seq;
  uint16_t crc;
  TelemetryPacket telem;
}; // 32 bytes

SecureCommand   secCmd;
SecureWaypointPacket secWpPkt;
SecureTelemetry secTelem;
uint8_t         telemSeq = 0;

// ── Target Angles and Flight State ──
float targetRoll     = 0.0f;
float targetPitch    = 0.0f;
float targetYaw      = 0.0f;
float targetThrottle = 0.0f;

float homeLat = 0.0f;
float homeLon = 0.0f;

uint16_t calculateRadioCRC16(const uint8_t *data, size_t length) {
  uint16_t crc = 0xFFFF;
  for (size_t i = 0; i < length; i++) {
    crc ^= (uint16_t)data[i] << 8;
    for (uint8_t j = 0; j < 8; j++) {
      if (crc & 0x8000) crc = (crc << 1) ^ 0x1021;
      else              crc = crc << 1;
    }
  }
  return crc;
}

unsigned long lastRFTime = 0;
bool imuActive = false;

// --- PCA9685 ---
Adafruit_PWMServoDriver pwm = Adafruit_PWMServoDriver();
#define SERVO_CH_YAW    0
#define SERVO_CH_ROLL_L 1
#define SERVO_CH_ROLL_R 2
#define SERVO_CH_FLAP_L 3
#define SERVO_CH_FLAP_R 4
#define SERVO_CH_PITCH_L 5
#define SERVO_CH_PITCH_R 6
#define SERVO_PULSE_MIN 102
#define SERVO_PULSE_MAX 512
#define SERVO_FREQUENCY  50

// ═══════════════════════════════════════════════════════
// VARIABLES DE ESTADO (Compartidas / Volatile)
// ═══════════════════════════════════════════════════════
volatile float latitude   = 0.0f;
volatile float longitude  = 0.0f;
volatile float altitudeM  = 0.0f;
volatile float speedKmph  = 0.0f;

volatile float pitchDeg   = 0.0f;   // Kalman pitch (grados)
volatile float rollDeg    = 0.0f;   // Kalman roll  (grados)
volatile float yawDeg     = 0.0f;   // Kalman yaw   (grados, 0–360)
volatile float totalGForce= 1.0f;

volatile float velX = 0.0f;   // Este (m/s)
volatile float velY = 0.0f;   // Norte (m/s)
volatile float velZ = 0.0f;   // Arriba (m/s)

float lastLat  = 0.0f, lastLon  = 0.0f, lastAlt  = 0.0f;
unsigned long lastGPSVelTime = 0;
bool firstGPSFix = true;
unsigned long lastIMUTime = 0;
float magneticDeclinationDeg = -6.0f; 

// Wind vector variables
volatile float windX = 0.0f;  // East wind (m/s)
volatile float windY = 0.0f;  // North wind (m/s)
volatile float windZ = 0.0f;  // Vertical wind (m/s)

// FreeRTOS thread safety Mutex
portMUX_TYPE sharedStateMutex = portMUX_INITIALIZER_UNLOCKED;

// ═══════════════════════════════════════════════════════
// FLY-BY-WIRE & PID (LAZO INTERNO)
// ═══════════════════════════════════════════════════════
class SlewLimiter {
  float current;
  float maxRate; 
public:
  SlewLimiter(float rate) : current(0), maxRate(rate) {}
  float update(float target, float dt) {
    float delta = target - current;
    float maxDelta = maxRate * dt;
    if (delta > maxDelta) current += maxDelta;
    else if (delta < -maxDelta) current -= maxDelta;
    else current = target;
    return current;
  }
};

class PIDController {
public:
  float kp, ki, kd;
  float integralMax;
  float integral;
  float lastMeasured;
  bool firstRun;

  PIDController(float p, float i, float d, float iMax) : 
    kp(p), ki(i), kd(d), integralMax(iMax), integral(0), lastMeasured(0), firstRun(true) {}

  float compute(float setpoint, float measured, float dt) {
    if (firstRun) {
      lastMeasured = measured;
      firstRun = false;
    }
    
    float error = setpoint - measured;
    float pOut = kp * error;
    
    integral += error * dt;
    if (integral > integralMax) integral = integralMax;
    else if (integral < -integralMax) integral = -integralMax;
    float iOut = ki * integral;
    
    float dMeasured = (measured - lastMeasured) / dt;
    float dOut = -kd * dMeasured;
    lastMeasured = measured;
    
    return pOut + iOut + dOut;
  }
};

SlewLimiter slewRoll(90.0f); 
SlewLimiter slewPitch(90.0f);
PIDController pidRoll(1.2f, 0.1f, 0.2f, 20.0f);
PIDController pidPitch(1.5f, 0.1f, 0.2f, 20.0f);

// ═══════════════════════════════════════════════════════
// NAVIGATION CONSTANTS
// ═══════════════════════════════════════════════════════
const float WP_CAPTURE_NEAR   = 8.0f;    // metros — confirmación de llegada
const float WP_CAPTURE_FAR    = 15.0f;   // metros — zona de desaceleración
const float STALL_SPEED       = 6.0f;    // m/s — velocidad mínima de seguridad recto

// Forward declarations
void handleFhssHopping();
void runL1Navigation();
void runOrbitNavigation();
void applySafetyGuards();
void estimateWind();
void readGPS();
void readMPU();
void updateTelemetry();
void setServoAngle(uint8_t channel, int angle);
void pushTelemetryAck();

// ═══════════════════════════════════════════════════════
// FREERTOS TASKS
// ═══════════════════════════════════════════════════════
void taskStabilization(void *pvParameters);
void taskNavigationComms(void *pvParameters);

void setup() {
  Serial.begin(115200);
  GPS_SERIAL.begin(9600, SERIAL_8N1, GPS_RX, GPS_TX);

  Wire.begin(21, 22);
  Wire.setClock(400000);

  mpu.Config(&Wire, bfs::Mpu9250::I2C_ADDR_PRIM);

  int mpuRetries = 10;
  while (!mpu.Begin() && mpuRetries > 0) {
    delay(100);
    mpuRetries--;
  }
  imuActive = (mpuRetries > 0);

  if (imuActive) {
    mpu.ConfigAccelRange(bfs::Mpu9250::ACCEL_RANGE_8G);
    mpu.ConfigGyroRange(bfs::Mpu9250::GYRO_RANGE_500DPS);
    mpu.ConfigDlpfBandwidth(bfs::Mpu9250::DLPF_BANDWIDTH_20HZ);
    mpu.ConfigSrd(19);   // ~50Hz

    delay(1000);

    mpu.Read();
    float ax = mpu.accel_x_mps2();
    float ay = mpu.accel_y_mps2();
    float az = mpu.accel_z_mps2();
    float initPitch = atan2f(ay, sqrtf(ax*ax + az*az)) * 57.2958f;
    float initRoll  = atan2f(-ax, az) * 57.2958f;
    kalmanPitch.setAngle(initPitch);
    kalmanRoll.setAngle(initRoll);
    kalmanYaw.setAngle(0.0f);
    lastIMUTime = millis();
  }

  if (!radio.begin()) { while (1); }
  radio.enableAckPayload();
  radio.enableDynamicPayloads();
  radio.setRetries(3, 5);
  radio.setPALevel(RF24_PA_LOW);
  radio.openWritingPipe(pipeTX);
  radio.openReadingPipe(1, pipeRX);
  radio.setChannel(fhssChannels[0]);
  radio.startListening();

  Preferences preferences;
  preferences.begin("pairing", false);
  if (preferences.isKey("shared_key")) {
    preferences.getBytes("shared_key", sharedKey, 16);
  }
  preferences.end();

  // Create thread-safe Tasks
  xTaskCreatePinnedToCore(
    taskStabilization, 
    "Stabilization", 
    4096, 
    NULL, 
    5, // Alta prioridad para lazo PID 50Hz
    NULL, 
    1  // Núcleo 1 (estabilización)
  );

  xTaskCreatePinnedToCore(
    taskNavigationComms, 
    "NavigationComms", 
    8192, 
    NULL, 
    2, // Prioridad normal para guiado/radio
    NULL, 
    0  // Núcleo 0 (cálculos vectoriales/comunicaciones)
  );

  lastRFTime = millis();
  lastPacketReceivedMs = millis();
}

void loop() {
  // Bucle principal vacío, FreeRTOS maneja las tareas en los dos núcleos
  vTaskDelay(pdMS_TO_TICKS(1000));
}

// ═══════════════════════════════════════════════════════
// CORE 1: ESTABILIZACIÓN RÁPIDA (50Hz)
// ═══════════════════════════════════════════════════════
void taskStabilization(void *pvParameters) {
  TickType_t xLastWakeTime = xTaskGetTickCount();
  const TickType_t xFrequency = pdMS_TO_TICKS(20); // Exactamente 20ms (50Hz)

  while (true) {
    float dt = 0.02f;

    if (imuActive) {
      readMPU();

      float rollLocal, pitchLocal;
      float targetRollLocal, targetPitchLocal, targetYawLocal, targetThrottleLocal;

      // Lectura y escritura atómica de variables compartidas
      portENTER_CRITICAL(&sharedStateMutex);
      targetRollLocal     = targetRoll;
      targetPitchLocal    = targetPitch;
      targetYawLocal      = targetYaw;
      targetThrottleLocal = targetThrottle;
      
      // Pasar actitud actual a navegación
      rollLocal           = rollDeg;
      pitchLocal          = pitchDeg;
      portEXIT_CRITICAL(&sharedStateMutex);

      // 1. Suavizar setpoints de usuario
      float smoothRoll = slewRoll.update(targetRollLocal, dt);
      float smoothPitch = slewPitch.update(targetPitchLocal, dt);

      // 2. Calcular PID
      float rollActuator = pidRoll.compute(smoothRoll, rollLocal, dt);
      float pitchActuator = pidPitch.compute(smoothPitch, pitchLocal, dt);
      float yawActuator = targetYawLocal; 

      // Mitigación de Torque Roll: rampa del acelerador para suavizar aceleraciones
      static float currentThrottle = 0.0f;
      float throttleDelta = targetThrottleLocal - currentThrottle;
      float maxThrottleDelta = 60.0f * dt; // max 60 unidades por segundo de rampa
      if (throttleDelta > maxThrottleDelta) currentThrottle += maxThrottleDelta;
      else if (throttleDelta < -maxThrottleDelta) currentThrottle -= maxThrottleDelta;
      else currentThrottle = targetThrottleLocal;

      // 3. Mezclador a Servos
      servo1Pos = (int)currentThrottle;
      servo2Pos = map(constrain(yawActuator, -40, 40),   -40, 40,  50, 130);
      servo3Pos = map(constrain(rollActuator, -45, 45),  -45, 45,  45, 135);
      servo4Pos = map(constrain(rollActuator, -45, 45),  -45, 45, 135,  45);  // invertido
      servo5Pos = 90;
      servo6Pos = 90;
      servo7Pos = map(constrain(pitchActuator, -30, 30), -30, 30,  60, 120);
      servo8Pos = map(constrain(pitchActuator, -30, 30), -30, 30,  60, 120);

      // 4. Aplicar al hardware
      esc.write(constrain(servo1Pos, 0, 180));
      setServoAngle(SERVO_CH_YAW,     servo2Pos);
      setServoAngle(SERVO_CH_ROLL_L,  servo3Pos);
      setServoAngle(SERVO_CH_ROLL_R,  servo4Pos);
      setServoAngle(SERVO_CH_FLAP_L,  servo5Pos);
      setServoAngle(SERVO_CH_FLAP_R,  servo6Pos);
      setServoAngle(SERVO_CH_PITCH_L, servo7Pos);
      setServoAngle(SERVO_CH_PITCH_R, servo8Pos);
    }

    vTaskDelayUntil(&xLastWakeTime, xFrequency);
  }
}

// ═══════════════════════════════════════════════════════
// CORE 0: NAVEGACIÓN Y COMUNICACIONES (10Hz)
// ═══════════════════════════════════════════════════════
static char setKeyLineBuf[32];
static uint8_t setKeyLineIdx = 0;

void handleSetKeyCommand(const char* line) {
  if (strncmp(line, "SET_KEY:", 8) != 0) return;
  const char* keyStr = line + 8;
  size_t keyLen = strlen(keyStr);
  uint8_t keyBytes[16] = {0};
  size_t copyLen = keyLen < 16 ? keyLen : 16;
  memcpy(keyBytes, keyStr, copyLen);

  Preferences prefs;
  prefs.begin("pairing", false);
  prefs.putBytes("shared_key", keyBytes, 16);
  prefs.end();

  memcpy(sharedKey, keyBytes, 16);
  Serial.println("[SEC] New key stored in NVS. Restarting...");
  delay(200);
  ESP.restart();
}

void parseSetKeySerial() {
  while (Serial.available()) {
    char ch = (char)Serial.peek();
    if ((uint8_t)ch == MAGIC_CMD || (uint8_t)ch == MAGIC_TELEM || (uint8_t)ch == MAGIC_WP) break;
    Serial.read();
    if (ch == '\n' || ch == '\r') {
      if (setKeyLineIdx > 0) {
        setKeyLineBuf[setKeyLineIdx] = '\0';
        handleSetKeyCommand(setKeyLineBuf);
        setKeyLineIdx = 0;
      }
    } else if (setKeyLineIdx < 30) {
      setKeyLineBuf[setKeyLineIdx++] = ch;
    }
  }
}
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

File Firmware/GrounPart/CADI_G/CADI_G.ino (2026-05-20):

#include <Arduino.h>
#include <SPI.h>
#include <RF24.h>
#include <nRF24L01.h>
#include <Bluepad32.h>
#include <Preferences.h>

// ═══════════════════════════════════════════════════════
// GLOBAL DEFINITIONS & MISSION STATE
// ═══════════════════════════════════════════════════════
const int MAX_WAYPOINTS = 16;

struct __attribute__((packed)) RouteWaypoint {
  float lat;
  float lon;
  float alt;
  uint8_t mode;      // 1=Waypoint, 2=Orbit
  uint8_t direction; // 0=CCW, 1=CW
  float radius;
};

RouteWaypoint waypointRoute[MAX_WAYPOINTS];
int waypointCount = 0;
int waypointIndex = 0;
bool routeLoop     = false;

enum NavigationMode { MODE_MANUAL = 0, MODE_WAYPOINT = 1, MODE_ORBIT = 2 };
NavigationMode currentMode = MODE_MANUAL;

// ── nRF24L01 Configuration ──
#define CE_PIN 5
#define CSN_PIN 4
RF24 radio(CE_PIN, CSN_PIN);
const byte pipeTX[6] = "CMD01";
const byte pipeRX[6] = "TEL01";

// ── FHSS Channels (Software hopping matching aircraft) ──
const uint8_t fhssChannels[8] = { 10, 25, 40, 55, 70, 85, 100, 115 };
uint8_t currentChannelIdx = 0;
unsigned long lastAckReceivedMs = 0;

// ── Gamepad & Origin State ──
ControllerPtr myControllers[BP32_MAX_GAMEPADS];
bool originEstablished = false;
float gpsOriginLat = 0.0f;
float gpsOriginLon = 0.0f;
float gpsOriginAlt = 0.0f;

// ── Link Quality Stats ──
static uint8_t lastTelemSeq = 0;
static uint32_t packetLossCount = 0;
static uint32_t packetTotalCount = 0;
uint8_t currentLossRate = 0;

Preferences preferences;

// ═══════════════════════════════════════════════════════
// BINARY SERIAL PROTOCOL (GCS PC <-> GCS ESP32)
// ═══════════════════════════════════════════════════════
const uint8_t MAGIC_START = 0xAA;
const uint8_t MAGIC_END   = 0x55;

// Packet types
const uint8_t PKT_CONFIG    = 0x01; // PC -> GCS ESP32 (config)
const uint8_t PKT_TELEMETRY = 0x02; // GCS ESP32 -> PC (telemetry)
const uint8_t PKT_ACK       = 0x03; // Bidirectional
const uint8_t PKT_NACK      = 0x04; // Bidirectional
const uint8_t PKT_MESSAGE   = 0x05; // GCS ESP32 -> PC (string log)
const uint8_t PKT_ROUTE     = 0x06; // PC -> GCS ESP32 (upload mission route)

// Master mode values
const uint8_t MASTER_DISCRETION = 0;
const uint8_t MASTER_MANUAL     = 1;
const uint8_t MASTER_AUTONOMOUS = 2;

// Order values
const uint8_t ORDER_NONE     = 0;
const uint8_t ORDER_WAYPOINT = 1;
const uint8_t ORDER_ORBIT    = 2;

const uint8_t DIR_CCW = 0;
const uint8_t DIR_CW  = 1;

// PC Configuration structure
struct __attribute__((packed)) ConfigPacket {
  uint8_t masterMode; // 0=discretion, 1=manual, 2=autonomous
  uint8_t order;      // 0=none, 1=waypoint, 2=orbit
  float waypoint_lat;
  float waypoint_lon;
  float waypoint_alt;
  uint8_t direction;  // 0=CCW, 1=CW
  float orbit_radius;
  float declination;  // Degrees
};

// Aircraft raw telemetry from flight controller
struct __attribute__((packed)) AircraftTelemetry {
  float   latitude;
  float   longitude;
  int16_t altitude;     // m * 10
  int16_t heading;      // deg * 10
  int16_t pitch;        // deg * 10
  int16_t roll;         // deg * 10
  int16_t gforce;       // G * 100
  int16_t velocityX;    // m/s * 100
  int16_t velocityY;    // m/s * 100
  int16_t velocityZ;    // m/s * 100
  uint8_t seq;
  uint8_t _pad[3];
}; // Total: 28 bytes

// Full GCS Telemetry Packet sent to PC
struct __attribute__((packed)) TelemetryPacket {
  float   latitude;
  float   longitude;
  float   altitude;
  float   yaw;
  float   pitch;
  float   roll;
  float   gforce;
  float   velocity_mag;
  float   pos_local_x;
  float   pos_local_y;
  float   pos_local_z;
  uint8_t currentMode;
  int16_t cmd_yaw;
  int16_t cmd_throttle;
  int16_t cmd_pitch;
  int16_t cmd_roll;
  uint8_t lossRate;
};

// CRC16 calculations
uint16_t calculateCRC16(const uint8_t *data, size_t length) {
  uint16_t crc = 0xFFFF;
  for (size_t i = 0; i < length; i++) {
    crc ^= (uint16_t)data[i] << 8;
    for (uint8_t j = 0; j < 8; j++) {
      if (crc & 0x8000) crc = (crc << 1) ^ 0x1021;
      else              crc = crc << 1;
    }
  }
  return crc;
}

uint16_t calculateRadioCRC16(const uint8_t *data, size_t length) {
  return calculateCRC16(data, length);
}

// Serial Buffering
const size_t SERIAL_BUFFER_SIZE = 512;
uint8_t serialBuffer[SERIAL_BUFFER_SIZE];
size_t serialBufferIndex = 0;

ConfigPacket lastConfig = {MASTER_DISCRETION, ORDER_NONE, 0.0f, 0.0f, 0.0f, DIR_CCW, 30.0f, -6.0f};
bool configReceived = false;

// ═══════════════════════════════════════════════════════
// ROUTE UPLOAD STATE MACHINE
// ═══════════════════════════════════════════════════════
enum UploadState {
  UPLOAD_IDLE,
  UPLOAD_SENDING
};

UploadState uploadState = UPLOAD_IDLE;
int uploadIndex = 0;
unsigned long lastUploadAttemptMs = 0;
int uploadRetries = 0;

// ═══════════════════════════════════════════════════════
// SECURITY (XXTEA ENCRYPTION)
// ═══════════════════════════════════════════════════════
uint32_t sharedKey[4] = { 0x58444630, 0x30314B45, 0x595F3230, 0x32362121 }; // "XDF001KEY_2026!!"
#define XXTEA_DELTA 0x9e3779b9
#define XXTEA_MX (((z>>5^y<<2) + (y>>3^z<<4)) ^ ((sum^y) + (sharedKey[(p&3)^e] ^ z)))

void btea(uint32_t *v, int n) {
  uint32_t y, z, sum;
  unsigned p, rounds, e;
  if (n > 1) {
    rounds = 6 + 52/n;
    sum = 0;
    z = v[n-1];
    do {
      sum += XXTEA_DELTA;
      e = (sum >> 2) & 3;
      for (p=0; p<n-1; p++) {
        y = v[p+1];
        z = v[p] += XXTEA_MX;
      }
      y = v[0];
      z = v[n-1] += XXTEA_MX;
    } while (--rounds);
  } else if (n < -1) {
    n = -n;
    rounds = 6 + 52/n;
    sum = rounds*XXTEA_DELTA;
    y = v[0];
    do {
      e = (sum >> 2) & 3;
      for (p=n-1; p>0; p--) {
        z = v[p-1];
        y = v[p] -= XXTEA_MX;
      }
      z = v[n-1];
      y = v[0] -= XXTEA_MX;
      sum -= XXTEA_DELTA;
    } while (--rounds);
  }
}

// ── Secure Radio Headers ──
const uint8_t MAGIC_CMD   = 0xAA;
const uint8_t MAGIC_TELEM = 0xBB;
const uint8_t MAGIC_WP    = 0xAC;

struct __attribute__((packed)) SecureCommand {
  uint8_t  magic;
  uint8_t  seq;
  uint16_t crc;
  int16_t  targetRoll;
  int16_t  targetPitch;
  int16_t  targetYaw;
  int16_t  targetThrottle;
  float    homeLat;
  float    homeLon;
  int16_t  declinationX10;
  uint8_t  navMode;        // 0=MANUAL, 1=WAYPOINT, 2=ORBIT
  uint8_t  cmdFlags;       // Bit 0 = Reset route index
}; // Total: 24 bytes (6 words)

struct __attribute__((packed)) SecureWaypointPacket {
  uint8_t  magic;          // MAGIC_WP = 0xAC
  uint8_t  seq;
  uint16_t crc;
  uint8_t  wpIndex;        // 0..15
  uint8_t  totalWps;
  uint8_t  routeLoop;      // 0=no, 1=yes
  uint8_t  mode;           // NavigationMode (0=MANUAL, 1=WAYPOINT, 2=ORBIT)
  RouteWaypoint wp;        // 18 bytes
  uint8_t  _pad[2];        // Pad to 28 bytes (multiple of 4)
}; // Total: 28 bytes (7 words)

struct __attribute__((packed)) SecureTelemetry {
  uint8_t  magic;
  uint8_t  seq;
  uint16_t crc;
  AircraftTelemetry telem;
}; // 32 bytes
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

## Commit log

2025-12-22 Create PCB
2025-12-31 Create control pcb.txt
2026-01-06 Track large files with Git LFS
    [XDF-001.kicad_pcb]
2026-01-07 Added some files
    [XDF-001.FCStd]
2026-01-07 Added BOM archive in .xlsx format
    [BOM.xlsx]
2026-01-07 Attempted to build .exe package
    [BOM.xlsx, XDF-001.FCStd]
2026-01-24 UPDATE CAD DESING
    [XDF-001.FCStd]
2026-02-05 Modified CAD files and add personalized 3d models for the PCB
    [BOM.xlsx, Pin Header.FCStd, Pin socket.FCStd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]
2026-02-10 Reorganized the repository and update README
    [BOM.xlsx, MP1584EN-Assembly.step, MP1584EN.FCStd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]
2026-02-11 Last details before summit
    [BOM.csv, BOM.xlsx, PCB.FCStd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]
2026-02-19 Added BOM table in README, added images and update wiring diagrams
2026-02-19 Added Wiring Diagram images
2026-02-19 UPDATE Wiring_Diagram
2026-02-24 feat: Create initial KiCad project for XDF-001, including the project file, schematic, and PCB layout.
    [XDF-001.kicad_pcb, XDF-001.kicad_sch]
2026-03-01 feat: Add M3 and M4 screws to the BOM and README, and create the initial CAD root file.
    [BOM.csv, BOM.xlsx, XDF-001.FCStd]
2026-03-05 Added Links to BOM.csv
    [BOM.csv]
2026-03-08 Updated BOM, PCB Files for include capacitors and connectors, added HUD Functions
    [BOM.csv, BOM.xlsx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]
2026-03-13 Crated NAV System Visualization APP and fix responsive in XDF-001 Control
    [XDF-001.FCStd]
2026-03-13 Change NAVSystem Visualization folder name, added tailwind CSS stile and correct mistakes
    [main.js]
2026-03-13 updated bom
    [BOM.csv]
2026-03-15 Updated CAD folder and created construction manual
    [Ala.FCStd, MP1584EN.FCStd, MPU9250.FCStd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]
2026-03-21 feat(CADI): autonomous fixed-wing navigation system with vector guidance, Kalman attitude/velocity fusion, encrypted RF link and multi-waypoint routing
    - Implement 6-step vector navigation (L1 factor, adaptive pitch, cross-wind PI, two-stage waypoint capture)
    - Add orbit mode with 5-phase state machine and PD radius controller
    - Fuse GPS+IMU velocity in aircraft (Kalman 3-axis + smoothing buffer)
    - Add 2-state Kalman attitude filter (pitch/roll/yaw) with high-G accel inhibit
    - Encrypt RF link with XXTEA + CRC16-CCITT, anti-replay seq counter
    - Implement fly-by-wire inner loop (PID + SlewLimiter at 50Hz) in CADI_A
    - Add autonomous RTL failsafe with GPS bearing guidance and loiter
    - Add geofen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
    [CADI_A.ino, CADI_A_Test.ino, CADI_G.ino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]
2026-03-24 Fix compilations errors of CADI_G
    [CADI_G.ino]
2026-03-24 Added debug station and corrected serial protocol
    [CADI_A.ino, CADI_G.ino, main.js]
2026-05-20 feat: migrate navigation to onboard ESP32, implement active failsafes, and integrate 3D WebGL dashboard
    [CADI_A.ino, CADI_G.ino]
2026-05-20 build: generate PCB manufacturing files, update BOM, and package application releases
    [BOM.csv, BOM.xlsx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]
